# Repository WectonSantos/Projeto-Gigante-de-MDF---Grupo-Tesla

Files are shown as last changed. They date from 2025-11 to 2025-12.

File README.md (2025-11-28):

🛠️ Gigante de MDF – Projeto de Programação de Hardware 2025 - Grupo Tesla 

Projeto desenvolvido para a disciplina Programação de Hardware, utilizando o microcontrolador ATmega328P e envolvendo mecânica, eletrônica e firmware embarcado.

📌 Sobre o Projeto
O objetivo deste trabalho foi aplicar, na prática, os conteúdos estudados ao longo do semestre, criando um robô móvel (“Gigante de MDF”) capaz de:

• Locomover-se por meio de motores controlados via PWM
• Emitir feixes de laser vermelho (≤ 300 mW)
• Detectar impactos recebidos por lasers adversários
• Gerenciar um sistema de “vidas” por LEDs
• Realizar reações automáticas ao ser atingido

O foco principal do projeto foi o desenvolvimento do firmware, sem depender de shields prontos, bibliotecas externas não autorizadas ou soluções prontas da comunidade Arduino.

🚗 Estrutura Mecânica
O robô construído segue o conjunto de requisitos mecânicos:

• Dimensões máximas de 200 × 200 × 200 mm
• Sistema com 2 a 4 rodas, capaz de realizar movimentação no próprio eixo
• “Arma” laser posicionada no centro do robô, a 100 mm de altura
• Receptor de luz instalado ao lado direito da arma, com difusor de 20 mm
• Estrutura baseada em MDF, com cortes e montagem conforme projeto disponibilizado

🧠 Firmware e Programação
O firmware foi desenvolvido inteiramente do zero, com base no datasheet oficial da Microchip, sem bibliotecas prontas (exceto as eventualmente autorizadas pelo professor).
O código atende às seguintes especificações:

✔️ Microcontrolador
• ATmega328P
✔️ Requisitos de Programação
• Controle dos motores via PWM de hardware
• Laser temporizado por Timer
• Receptor de luz com rotina de interrupção
• Delay de segurança de 5s após cada acerto
• Gestão de LEDs e lógica de “vidas”
• Rotina de giro automático de 180°
• Reset de vidas via interrupção externa
• Código completamente documentado em Doxygen

📚 Documentação
A documentação completa do software foi gerada usando Doxygen e está disponível em:
/Documentacao/doxygen/

👥 Integrantes – Grupo Tesla
• Rafael Wippich
• Thiago Taveira
• Wecton Santos

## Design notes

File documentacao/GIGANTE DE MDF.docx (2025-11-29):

GIGANTE DE MDF

Rafael Wippich Jorge Alonso

Thiago Taveira Fernandes Amorim Justo

Wecton da Silva Santos

# 1. Introdução

O projeto Gigantes de MDF consiste no desenvolvimento completo de um robô móvel construído em MDF, equipado com um sistema de movimentação por motores DC controlados por PWM, um sistema de “arma laser” baseado em diodo emissor de luz vermelha e um sistema de detecção via receptor LDR com difusor.

O objetivo principal deste trabalho é aplicar, de forma prática, os conceitos aprendidos na disciplina de Programação de Hardware, utilizando o microcontrolador ATmega328p sem uso de shields ou módulos prontos, exceto componentes básicos necessários ao funcionamento.

Toda a eletrônica, firmware e documentação foram projetados, desenvolvidos e implementados pelo grupo.

# 2. Estrutura Mecânica

Apresentaremos a concepção mecânica do robô, seus limites dimensionais e a organização física dos componentes.

## 2.1 Dimensões e Construção

- Dimensões máximas: 200 × 200 × 200 mm

- Material utilizado: MDF de 3mm, cortado a laser.

- Modelo de referência utilizado: https://fabmanager.unisanta.br/#!/projects/estrutura-carro-robo

- Esquema mecânico utilizado no projeto:

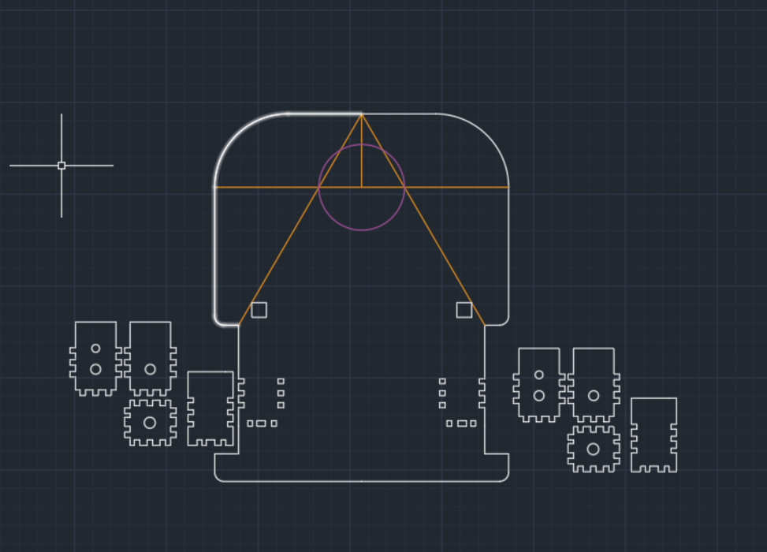
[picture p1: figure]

## 2.2 Sistema de Movimentação

- Quantidade de rodas: 2

- Motores utilizados: 2x Motor DC 3-6V

## 2.3 Sistema de Arma Laser

- Posição: centro do robô

- Altura em relação à base: 100 mm

- Tipo de laser utilizado: Laser vermelho

## 2.4 Sistema de Detecção

- Sensor de luz: LDR de 20 mm

- Posição: lado direito da arma laser

# 3. Arquitetura Eletrônica

- Microcontrolador: ATmega328P

- Driver de Motor: ci L293D

- Receptor de Luz: LDR 20mm

- Laser: Módulo Laser 650nm 5mw Md-lsr650nm

- Sistema de Vidas: 3x leds de 5mm

- Sistema de Movimentação: Módulo Bluetooth HC-06

- Sistema Reset: 1x Botão 6mm

- Diagrama Eletrônico Geral:

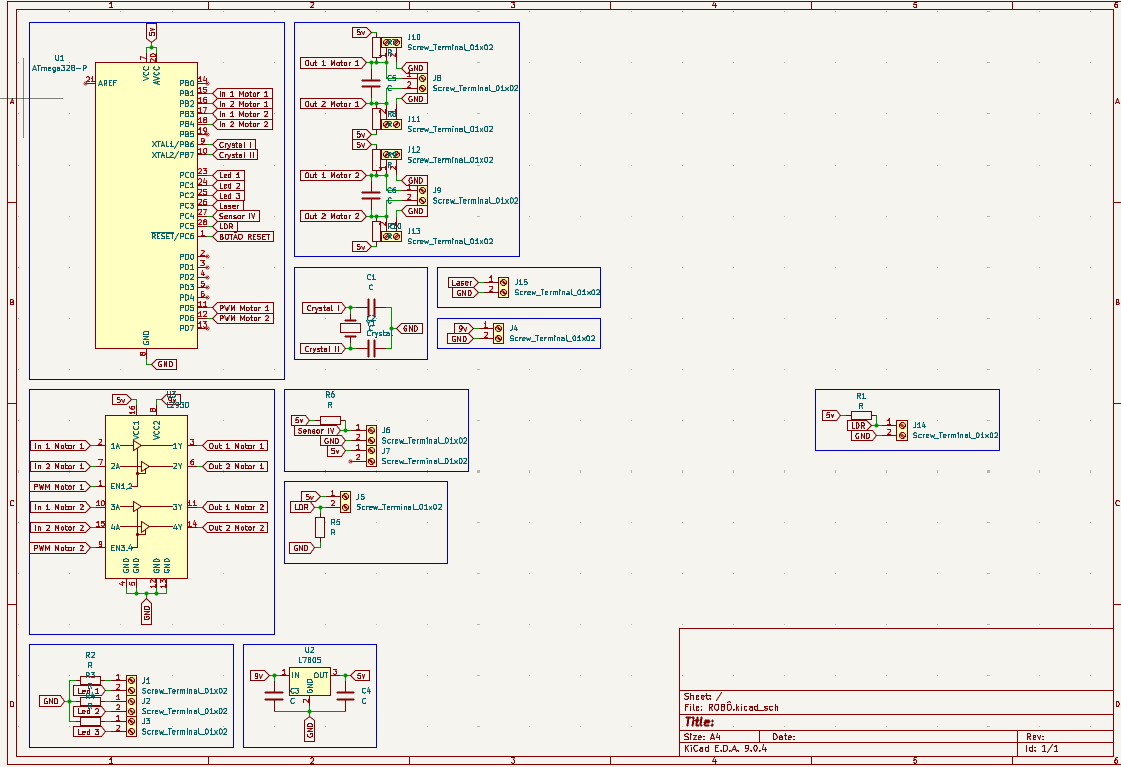
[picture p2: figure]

# 4. Firmware

O firmware desenvolvido para o projeto foi inteiramente escrito na linguagem C, utilizando acesso direto aos registradores do microcontrolador ATmega328P, conforme exigido pelo edital. A estrutura do código foi organizada em módulos independentes, permitindo fácil manutenção e leitura, além de garantir funcionamento eficiente e controle preciso dos periféricos essenciais.

Antes de ser gravado na placa, o firmware passou por uma etapa de simulação, que permitiu validar a lógica principal, testar estados da máquina de controle e verificar o comportamento dos módulos de acionamento, leitura de sensores e gerenciamento do laser. Essa fase reduziu significativamente retrabalhos na parte física, garantindo que os primeiros testes na plataforma real ocorressem com maior estabilidade. Após essa etapa, o código foi então carregado e testado diretamente no hardware, possibilitando ajustes finais de temporização, calibração e resposta do sistema.

Durante o desenvolvimento, foram utilizados os seguintes softwares:

- Microchip Studio: Ambiente principal de programação, gerenciamento do projeto, escrita, compilação e gravação do firmware no microcontrolador.

- SimulIDE: Ferramenta usada para simulação dos circuitos e execução preliminar do firmware antes da etapa prática.

- GitHub: Plataforma de versionamento utilizada para armazenar o código-fonte, manter o histórico de alterações, documentar o projeto e facilitar a colaboração entre os integrantes do grupo.

- Doxygen: Ferramenta utilizada para gerar automaticamente a documentação do firmware a partir de comentários estruturados inseridos diretamente no código-fonte. Com ela, foi possível organizar descrições de funções, módulos, estruturas, variáveis e fluxos internos do programa de forma clara e navegável.

Esse conjunto de ferramentas permitiu um desenvolvimento estruturado, controlado e eficiente, garantindo confiabilidade no firmware final entregue junto ao robô.

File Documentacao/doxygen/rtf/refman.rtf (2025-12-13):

Gigante de MDF - Grupo Tesla

AUTHOR
Versão 2.0

Sumário

Table of contents

Índice dos Arquivos
Lista de Arquivos
Esta é a lista de todos os arquivos e suas respectivas descrições:
C:/Users/Wecton/Desktop/Projeto-Gigante-de-MDF---Grupo-Tesla/main.c pagenum

Arquivos
Referência do Arquivo C:/Users/Wecton/Desktop/Projeto-Gigante-de-MDF---Grupo-Tesla/main.c
AAAAAAAAAAAAAAAAAAAA#include <avr/io.h>
#include <avr/interrupt.h>

#include <stdlib.h>

Funções
void ledsVida ()
void atualizaLedsVida ()
void motores ()
void pararMotores ()
void ligaMotoresHorario ()
void ligaMotoresAntiHorario ()
void giraEsquerda ()
void giraDireita ()
void girar360 ()
void laser ()
void timer1_init ()
void timer1_stop ()
ISR (TIMER1_COMPA_vect)
void timer2_init ()
void timer2_stop ()
ISR (TIMER2_COMPA_vect)
void adc_init ()
uint16_t adc_read (uint8_t canal)
void executaPedidoSequencia ()
void UART_Init ()
char UART_Receive ()
void UART_Transmit (char data)
void UART_SendString (const char *s)
void UART_SendInt (uint16_t v)
void controle ()
void botaoReset_init ()
ISR (INT1_vect)
void fim ()
int main (void)
Variáveis
uint8_t vidas = 3
uint8_t fimDeJogo = 0
volatile char comandoAtual = 'T'
volatile uint8_t estado = 0
volatile uint32_t contador = 0
volatile uint8_t seqRequisitada = 0

AAAAAAAAABAAAAAAAAABFunções
void adc_init ()
AAAAAAAAACAAAAAAAAAC
186 {
187 ADMUX = (1<<REFS0);
188 ADCSRA = (1<<ADEN)|(1<<ADPS2)|(1<<ADPS1)|(1<<ADPS0);
189 }
uint16_t adc_read (uint8_t canal)
AAAAAAAAADAAAAAAAAAD
191 {
192 ADMUX = (ADMUX & 0xF0) | (canal & 0x0F);
193 ADCSRA |= (1<<ADSC);
194 while (ADCSRA & (1<<ADSC));
195 return ADC;
196 }
void atualizaLedsVida ()
AAAAAAAAAEAAAAAAAAAE
32 {
33 if (vidas >= 3){
34 PORTC |= (1<<PC0) | (1<<PC1) | (1<<PC2);
35 }
36 else if (vidas == 2){
37 PORTC &= ~(1<<PC0);
38 PORTC |= (1<<PC1) | (1<<PC2);
39 }
40 else if (vidas == 1){
41 PORTC &= ~((1<<PC0)|(1<<PC1));
42 PORTC |= (1<<PC2);
43 }
44 else {
45 PORTC &= ~( (1<<PC0) | (1<<PC1) | (1<<PC2) );
46 fimDeJogo = 1;
47 }
48 }
void botaoReset_init ()
AAAAAAAAAFAAAAAAAAAF
263 {
264 DDRD &= ~(1<<PD3);
265 PORTD |= (1<<PD3);
266 EICRA |= (1<<ISC11);
267 EIMSK |= (1<<INT1);
268 }
void controle ()
AAAAAAAAAGAAAAAAAAAG
245 {
246 if (UCSR0A & (1<<RXC0))
247 comandoAtual = UDR0;
248
249 switch (comandoAtual) {
250 case 'F': case 'f': ligaMotoresHorario(); break;
251 case 'B': case 'b': ligaMotoresAntiHorario(); break;
252 case 'L': case 'l': giraEsquerda(); break;
253 case 'R': case 'r': giraDireita(); break;
254 case 'T': case 't': pararMotores(); break;
255 case 'X': case 'x': pararMotores(); break;
256
257 default: break;
258 }
259 }
void executaPedidoSequencia ()
AAAAAAAAAHAAAAAAAAAH
200 {
201 if (seqRequisitada) return;
202
203 seqRequisitada = 1;
204 estado = 1;
205 contador = 0;
206
207 girar360();
208 vidas--;
209
210 timer2_init();
211 }
void fim ()
AAAAAAAAAIAAAAAAAAAI
278 {
279 while(1){
280 pararMotores();
281 estado = 2;
282 PORTC &= ~(1<<PC3);
283 timer1_stop();
284 }
285 }
void giraDireita ()
AAAAAAAAAJAAAAAAAAAJ
97 {
98 // Esquerdo anti-horário
99 PORTD &= ~(1<<PD6);
100 PORTD &= ~(1<<PD5);
101
102 // Direito horário
103 PORTB |= (1<<PB3);
104 PORTB &= ~(1<<PB4);
105 }
void giraEsquerda ()
AAAAAAAAAKAAAAAAAAAK
86 {
87 // Esquerdo horário
88 PORTD |= (1<<PD5);
89 PORTD &= ~(1<<PD6);
90
91 // Direito anti-horário
92 PORTB &= ~(1<<PB4);
93 PORTB &= ~(1<<PB3);
94
95 }
void girar360 ()
AAAAAAAAALAAAAAAAAAL
107 {
108 // Esquerdo horário
109 PORTD |= (1<<PD5);
110 PORTD &= ~(1<<PD6);
111
112 // Direito anti-horário
113 PORTB |= (1<<PB4);
114 PORTB &= ~(1<<PB3);
115 }
ISR (INT1_vect )
AAAAAAAAAMAAAAAAAAAM
270 {
271 if (estado == 2) return;
272 vidas = 3;
273 atualizaLedsVida();
274 }
ISR (TIMER1_COMPA_vect )
AAAAAAAAANAAAAAAAAAN
137 {
138 if (estado == 0){
139 PORTC ^= (1<<PC3);
140 }
141 }
ISR (TIMER2_COMPA_vect )
AAAAAAAAAOAAAAAAAAAO
158 {
159 if (estado == 0 && seqRequisitada == 0) return;
160
161 contador++;
162
163 if (estado == 1){
164 if (contador >= 1000){
165 pararMotores();
166 PORTC &= ~(1<<PC3);
167 timer1_stop();
168 estado = 2;
169 contador = 0;
170 }
171 }
172 else if (estado == 2){
173 if (contador >= 5000){
174 estado = 0;
175 seqRequisitada = 0;
176 contador = 0;
177 timer1_init();
178 timer2_stop();
179 PORTC &= ~(1<<PC3);
180 }
181 }
182 }
void laser ()
AAAAAAAAAPAAAAAAAAAP
120 {
121 DDRC |= (1<<PC3);
122 }
void ledsVida ()
AAAAAAAAAQAAAAAAAAAQ
26 {
27 DDRC |= (1 << PC0) | (1 << PC1) | (1 << PC2);
28
29 PORTC |= (1<<PC0) | (1<<PC1) | (1<<PC2);
30 }
void ligaMotoresAntiHorario ()
AAAAAAAAARAAAAAAAAAR
76 {
77 // Esquerdo anti-horário
78 PORTD |= (1<<PD6);
79 PORTD &= ~(1<<PD5);
80
81 // Direito anti-horário
82 PORTB |= (1<<PB4);
83 PORTB &= ~(1<<PB3);
84 }
void ligaMotoresHorario ()
AAAAAAAAASAAAAAAAAAS
66 {
67 // Motor esquerdo horário
68 PORTD |= (1<<PD5);
69 PORTD &= ~(1<<PD6);
70
71 // Motor direito horário
72 PORTB |= (1<<PB3);
73 PORTB &= ~(1<<PB4);
74 }
int main (void )
AAAAAAAAATAAAAAAAAAT
289 {
290 ledsVida();
291 motores();
292 laser();
293 adc_init();
294 timer1_init();
295 UART_Init();
296 botaoReset_init();
297
298 uint16_t valorLDR;
299 uint8_t luzAlta = 0;
300
301 while (1)
302 {
303 // BLOQUEIA LEITURA DO LDR DURANTE SEQUÊNCIA
304 if (estado == 0) {
305
306 valorLDR = adc_read(5);
307
308 if (valorLDR > 900 && seqRequisitada == 0) {
309 executaPedidoSequencia();
310 }
311
312 // permite controle bluetooth só no modo normal
313 controle();
314 }
315
316 atualizaLedsVida();
317
318 if (fimDeJogo)
319 fim();
320 }
321
322 }
void motores ()
AAAAAAAAAUAAAAAAAAAU
52 {
53 DDRB |= (1<<PB3) | (1<<PB4); // Motor direito
54 DDRD |= (1<<PD5) | (1<<PD6); // Motor esquerdo
55
56 // Inicialmente desligado
57 PORTB &= ~((1<<PB3)|(1<<PB4));
58 PORTD &= ~((1<<PD5)|(1<<PD6));
59 }
void pararMotores ()
AAAAAAAAAVAAAAAAAAAV
61 {
62 PORTB &= ~((1<<PB3)|(1<<PB4));
63 PORTD &= ~((1<<PD5)|(1<<PD6));
64 }
void timer1_init ()
AAAAAAAAAWAAAAAAAAAW
124 {
125 TCCR1B |= (1<<WGM12);
126 OCR1A = 15624;
127 TIMSK1 |= (1<<OCIE1A);
128 TCCR1B |= (1<<CS12)|(1<<CS10);
129 sei();
130 }
void timer1_stop ()
AAAAAAAAAXAAAAAAAAAX
132 {
133 TIMSK1 &= ~(1<<OCIE1A);
134 TCCR1B = 0;
135 }
void timer2_init ()
AAAAAAAAAYAAAAAAAAAY
145 {
146 TCCR2A = (1<<WGM21);
147 OCR2A = 249;
148 TIMSK2 |= (1<<OCIE2A);
149 TCCR2B = (1<<CS22);
150 sei();
151 }
void timer2_stop ()
AAAAAAAAAZAAAAAAAAAZ
153 {
154 TIMSK2 &= ~(1<<OCIE2A);
155 TCCR2B = 0;
156 }
void UART_Init ()
AAAAAAAABAAAAAAAAABA
215 {
216 uint16_t ubrr = 103;
217 UBRR0H = (unsigned char)(ubrr>>8);
218 UBRR0L = (unsigned char)ubrr;
219 UCSR0B = (1<<RXEN0)|(1<<TXEN0);
220 UCSR0C = (1<<UCSZ01)|(1<<UCSZ00);
221 }
char UART_Receive ()
AAAAAAAABBAAAAAAAABB
223 {
224 while (!(UCSR0A & (1<<RXC0)));
225 return UDR0;
226 }
void UART_SendInt (uint16_t v)
AAAAAAAABCAAAAAAAABC
237 {
238 char buf[10];
239 itoa(v, buf, 10);
240 UART_SendString(buf);
241 }
void UART_SendString (const char * s)
AAAAAAAABDAAAAAAAABD
233 {
234 while(*s) UART_Transmit(*s++);
235 }
void UART_Transmit (char data)
AAAAAAAABEAAAAAAAABE
228 {
229 while (!(UCSR0A&(1<<UDRE0)));
230 UDR0 = data;
231 }

AAAAAAAABFAAAAAAAABFVariáveis
volatile char comandoAtual = 'T'
AAAAAAAABGAAAAAAAABGvolatile uint32_t contador = 0
AAAAAAAABHAAAAAAAABHvolatile uint8_t estado = 0
AAAAAAAABIAAAAAAAABIuint8_t fimDeJogo = 0
AAAAAAAABJAAAAAAAABJvolatile uint8_t seqRequisitada = 0
AAAAAAAABKAAAAAAAABKuint8_t vidas = 3
AAAAAAAABLAAAAAAAABL

Referência do Arquivo C:/Users/Wecton/Desktop/Projeto-Gigante-de-MDF---Grupo-Tesla/README.md
AAAAAAAABMAAAAAAAABM
Sumário
INDEX

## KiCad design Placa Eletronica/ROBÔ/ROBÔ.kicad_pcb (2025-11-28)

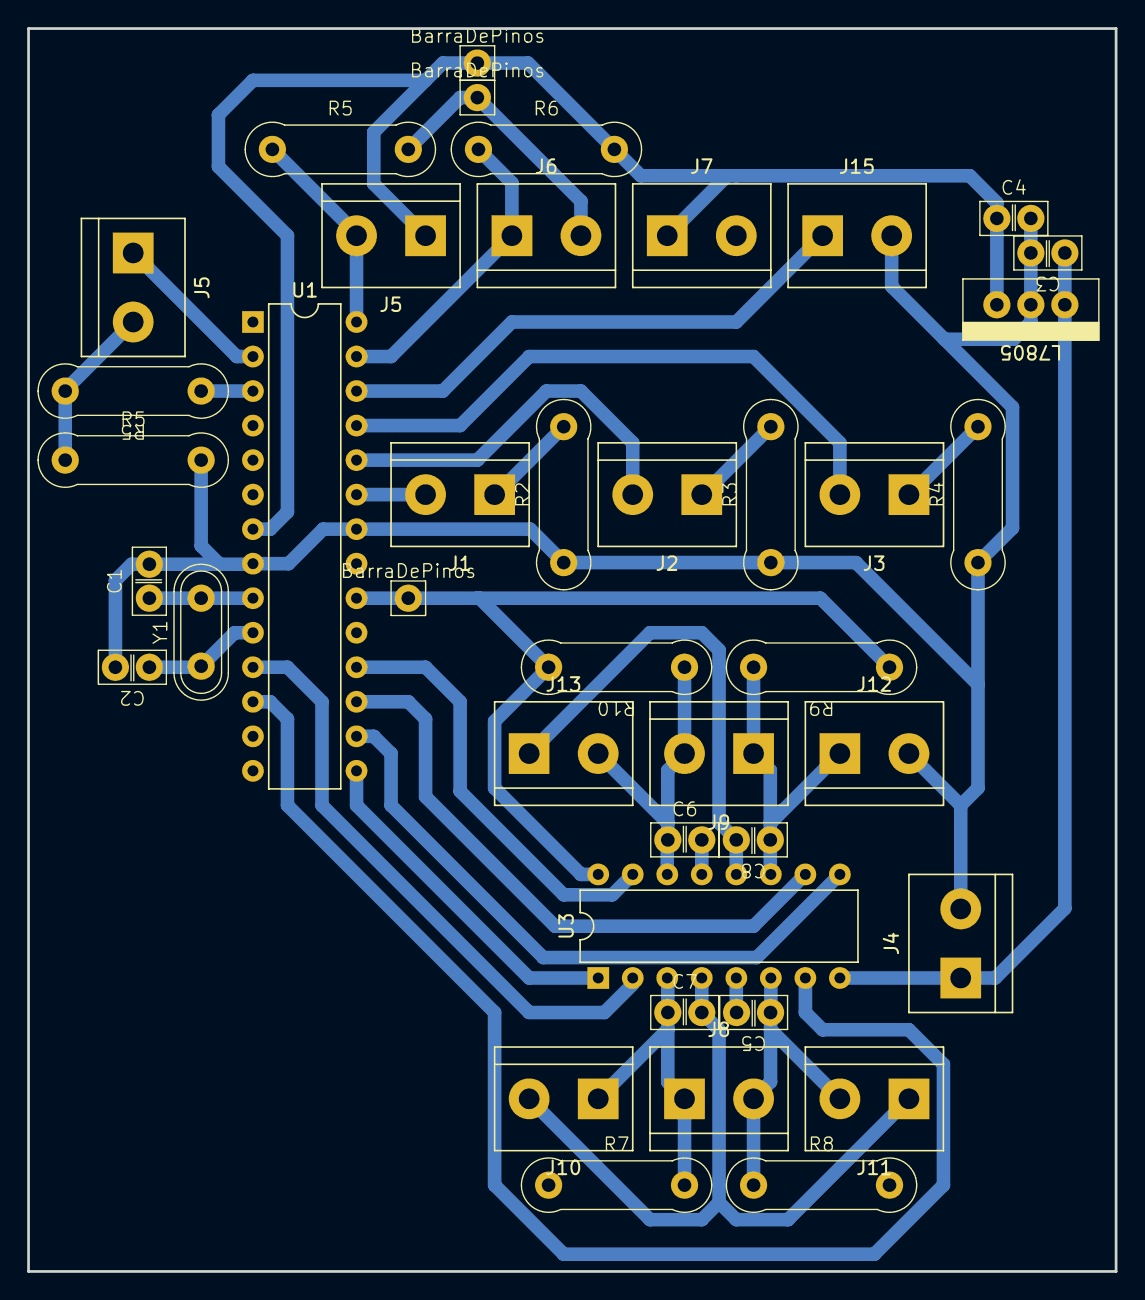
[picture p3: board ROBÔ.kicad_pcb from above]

Board: 2 copper layers, 80.0 x 91.4 mm, 41 parts (0 on the bottom side), 27 nets.

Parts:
BarraDePinos: DistânciaEntreFuros:_2,54mm; BarraDePinos
BarraDePinos#2, BarraDePinos#3: DistânciaEntreFuros:_2,54mm; BarraDePinos
C1, C2, C3, C4, C5, C6, C7, C8: C; CapacitorCerâmico-100nF_ou_0,1uF
J1, J2, J3, J4, J5, J5#2, J6, J7, J8, J9, J10, J11, J12, J13, J15: Screw_Terminal_01x02; TerminalBlock_bornier-2_P5.08mm
R2, R3, R4, R5, R5#2, R5#3, R6, R7, R8, R9, R10: R; Resistor
U1: ATmega328-P; DIP-28_W7.62mm
U2: L7805; ReguladorDeTensão-L7805_5V
U3: L293D; DIP-16_W7.62mm
Y1: Crystal; CristalOscilador16MHz

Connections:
5v: BarraDePinos#2.1, BarraDePinos#3.1, C4.IN, J5.1, J7.1, R6.2, R7.1, R8.2, R9.1, R10.2, U1.7 (VCC), U1.20 (AVCC), U2.OUTPUT, U3.16 (VCC1)
9v: C3.IN, J4.1, U2.INPUT, U3.8 (VCC2)
Crystal I: C1.IN, U1.9 (XTAL1/PB6), Y1.2
Crystal II: C2.IN, U1.10 (XTAL2/PB7), Y1.1
GND: BarraDePinos.1, C1.GND, C2.GND, C3.GND, C4.GND, C5.GND, C6.GND, C7.GND, C8.GND, J4.2, J6.2, J10.2, J11.1, J12.2, J13.1, J15.2, R2.1, R3.1, R4.1, R5#2.2, R5#3.2, U1.8 (GND), U1.22 (GND), U2.GND, U3.4 (GND), U3.5 (GND), U3.12 (GND), U3.13 (GND)
In 1 Motor 1: U1.11 (PD5), U3.2 (1A)
In 1 Motor 2: U1.17 (PB3), U3.10 (3A)
In 2 Motor 1: U1.12 (PD6), U3.7 (2A)
In 2 Motor 2: U1.18 (PB4), U3.15 (4A)
LDR: J5.2, R5#2.1, U1.28 (PC5)
Laser: J15.1, U1.26 (PC3)
Led 1: J1.2, U1.23 (PC0)
Led 2: J2.2, U1.24 (PC1)
Led 3: J3.2, U1.25 (PC2)
unnamed: J1.1, R2.2
unnamed: J2.1, R3.2
unnamed: J3.1, R4.2
Out 1 Motor 1: C7.IN, J8.1, J10.1, R7.2, U3.3 (1Y)
Out 1 Motor 2: C8.IN, J9.1, J12.1, R9.2, U3.11 (3Y)
Out 2 Motor 1: C5.IN, J8.2, J11.2, R8.1, U3.6 (2Y)
Out 2 Motor 2: C6.IN, J9.2, J13.2, R10.1, U3.14 (4Y)
PWM Motor 1: U1.15 (PB1), U3.1 (EN1,2)
PWM Motor 2: U1.16 (PB2), U3.9 (EN3,4)
RX: J5#2.1, U1.2 (PD0)
Sensor IV: J6.1, R6.1, U1.27 (PC4)
TX: R5.1, U1.3 (PD1)
Temp: J5#2.2, R5.2, R5#3.1

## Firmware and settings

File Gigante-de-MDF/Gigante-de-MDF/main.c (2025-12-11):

/*
 * projeto-prog-hardware.c
 *
 * Created: 13/10/2025 22:14:15
 * Author : Wecton
 */ 

#include <avr/io.h>
#include <avr/interrupt.h>
#include <stdlib.h> // APENAS PARA RETORNAR OS VALORES INT SEM ERROS NO BLUETOOTH, UTILIZANDO itoa

uint8_t vidas = 3;
uint8_t fimDeJogo = 0;
volatile char comandoAtual = 'T'; 

// SEQUÊNCIA: 0 = NORMAL, 1 = GIRANDO 1S, 2 = BLOQUEADO 5S
volatile uint8_t estado = 0;
volatile uint32_t contador = 0; // // CONTADOR EM MS
volatile uint8_t seqRequisitada = 0;// FLAG DE REQUISIÇÃO DA SEQUÊNCIA

// ROTINA QUE CONFIGURA OS LEDS DE VIDA
void ledsVida(){
	DDRC |= (1 << PC0); // LED 1 (SAÍDA)
	DDRC |= (1 << PC1); // LED 2 (SAÍDA)
	DDRC |= (1 << PC2); // LED 3 (SAÍDA)
	
	PORTC |= (1<< PC0); // LIGANDO LED 1
	PORTC |= (1<< PC1); // LIGANDO LED 1
	PORTC |= (1<< PC2); // LIGANDO LED 1
}
// ROTINA QUE CONFIGURA OS MOTORES
void motores() {
	DDRB |= (1<<PB1) | (1<<PB2) | (1<<PB3) | (1<<PB4);
	DDRD |= (1<<PD5) | (1<<PD6);

	// Desliga tudo ANTES de qualquer comando Bluetooth
	PORTB &= ~((1<<PB1)|(1<<PB2)|(1<<PB3)|(1<<PB4));
	OCR0A = 0;
	OCR0B = 0;
}


// BOTÕES PREVIAMENTE QUE SERÃO TROCADOS PELO VALOR RECEBIDO DO CONTROLE
void botoes(){
	DDRB &= ~(1 << PB6);
	DDRB &= ~(1 << PB0);
	DDRD &= ~(1 << PD4);
}

// ROTINA QUE CONFIGURA O LASER
void laser(){
	DDRC |= (1 << PC3); // LASER PORTA C3 (CTC)
}

// ROTINA LDR

void adc_init(void) {
	ADMUX = (1 << REFS0); 		
	//ADMUX &= ~(1 << ADLAR);   // alinhamento à direita (modo normal)

	ADCSRA = (1 << ADEN) | (1 << ADPS2) | (1 << ADPS1) | (1 << ADPS0); // prescaler 128 (16MHz/128=125kHz)
	//DIDR0 = (1 << ADC4D);
	//DDRC &= ~(1 << PC4); 
}

uint16_t adc_read(uint8_t canal) {
	//ADMUX = (1 << REFS0) | (canal & 0x0F);
	ADMUX = (ADMUX & 0xF0) | (canal & 0x0f);
	ADCSRA |= (1 << ADSC);
	while (ADCSRA & (1 << ADSC));
	return ADC; 
}

void atualizaLedsVida() {
	if (vidas >= 3){
		PORTC |= (1 << PC0) | (1 << PC1) | (1 << PC2);
	}else if (vidas == 2) {
		PORTC |= (1 << PC1) | (1 << PC2);
		PORTC &= ~(1 << PC0);
	}else if (vidas == 1) {
		PORTC |= (1 << PC2);
		PORTC &= ~((1 << PC0) | (1 << PC1));
	}else{
		PORTC &= ~((1 << PC0) | (1 << PC1) | (1 << PC2));
		fimDeJogo = 1;
	}
}
// FIM ROTINA LDR

// ROTINA DOS MOTORES
void ligaMotoresHorario(){		
    // Motor esquerdo horário
    PORTB |=  (1<<PB1);
    PORTB &= ~(1<<PB2);

    // Motor direito horário
    PORTB |=  (1<<PB3);
    PORTB &= ~(1<<PB4);
}

void ligaMotoresAntiHorario(){
    // Motor esquerdo anti-horário
    PORTB |=  (1<<PB2);
    PORTB &= ~(1<<PB1);

    // Motor direito anti-horário
    PORTB |=  (1<<PB4);
    PORTB &= ~(1<<PB3);
}

void giraEsquerda() {
    // Motor esquerdo anti-horário
    PORTB |=  (1<<PB2);
    PORTB &= ~(1<<PB1);

    // Motor direito horário
    PORTB |=  (1<<PB3);
    PORTB &= ~(1<<PB4);
}

void giraDireita() {
    // Motor esquerdo horário
    PORTB |=  (1<<PB1);
    PORTB &= ~(1<<PB2);

    // Motor direito anti-horário
    PORTB |=  (1<<PB4);
    PORTB &= ~(1<<PB3);
}

void girar360() {
	// Motor 1 horário: IN1=1, IN2=0
	PORTB |=  (1<<PB1);
	PORTB &= ~(1<<PB2);

	// Motor 2 anti-horário: IN3=0, IN4=1
	PORTB &= ~(1<<PB3);
	PORTB |=  (1<<PB4);

	// PWM
	OCR0A = 200;  // motor 2
	OCR0B = 200;  // motor 1
}


void curvaDireita(){
	PORTB |= (1<<PB1)|(1<<PB3);
	PORTB &= ~((1<<PB2)|(1<<PB4));	
	// LIGA PWM
	OCR0A = 255;
	OCR0B = 77;
}
void curvaEsquerda(){
	PORTB |= (1<<PB1)|(1<<PB3);
	PORTB &= ~((1<<PB2)|(1<<PB4));
	// LIGA PWM
	OCR0A = 77;
	OCR0B = 255;
}

void pararMotores() {
	OCR0A = 0;
	OCR0B = 0;
	PORTB &= ~((1<<PB1)|(1<<PB2)|(1<<PB3)|(1<<PB4));
}


void verificaSentido(){
	if (PIND & (1 << PD4)) {
		ligaMotoresHorario();
	}
	else if (PINB & (1 << PB0)) {
		ligaMotoresAntiHorario();
	}//else if (PINB & (1 << PB6)){
		//ligaMotoresMeiaForca();  
	//}
	else {
		OCR0A = 0;
		OCR0B = 0;
		PORTB &= ~((1 << PB7) | (1 << PB5) | (1 << PB4) | (1 << PB0));
	}	
}
//FIM ROTINA DOS MOTORES

//ROTINA LASER MODO CTC
void timer1_init() {
	TCCR1B |= (1 << WGM12);  // CTC
	OCR1A = 15624;           // 1 SEGUNDO P/ PRESCALER 1024
	TIMSK1 |= (1 << OCIE1A); 
	TCCR1B |= (1 << CS12) | (1 << CS10); // PRESCALER 1024
	sei();
}

// DESLIGA O TIMER1 (PARA NÃO ALTERAR O LASER DURANTE BLOQUEIO)
void timer1_stop() {
	TIMSK1 &= ~(1 << OCIE1A);
	TCCR1B = 0;
}
// PISCA LASER SE ESTIVER EM MODO NORMAL == SEM BLOQUEIO
ISR(TIMER1_COMPA_vect) {
	if (estado == 0){
		PORTC ^= (1 << PC3);
	}
	//PORTC ^= (1 << PC3);  // ALTERNA ESTADO DO LED
}

// TICKS DE 1 MS PARA GERENCIAR A SEQUÊNCIA SEM DELAY
void timer2_init(void){
	TCCR2A = (1 << WGM21); // CTC
	OCR2A = 249; // COM PRESCALER 64 => 1MS
	TIMSK2 |= (1 << OCIE2A);
	TCCR2B = (1 << CS22); // PRESCALER 64
	sei();
}
// DESLIGA O TIMER2
void timer2_stop(void){
	TIMSK2 &= ~(1 << OCIE2A);
	TCCR2B = 0;
}

// CONTROLE DA SEQUÊNCIA (1S GIRANDO, 5S BLOQUEADO)
ISR(TIMER2_COMPA_vect){

	if (estado == 0 && seqRequisitada == 0) return; // SE NÃO HOUVER SEQUENCIA NÃO FAZ NADA

	contador++; 

	if (estado == 1) {
		// LDR RECEBEU VALOR ALTO E ESPERA 1S PARA COMPLETAR O GIRO 360
		if (contador >= 1000) {
			// APÓS O GIRO PARA MOTORES, DESLIGA LASER, INICIA BLOQUEIO
			pararMotores(); 
			PORTC &= ~(1 << PC3);// DESLIGA LASER
			timer1_stop(); // GARANTE QUE O TIMER1 NÃO VAI MAIS PISCAR
			estado = 2; // ALTERNA PARA O ESTADO DE BLOQUEIO
			contador = 0; 
		}
	} else if (estado == 2) { // ESTÁ BLOQUEADO, AGUARDA 5S
		if (contador >= 5000) {
			// AO SAIR DO BLOQUEIO RETORNA AO MODO NORMAL
			estado = 0;
			contador = 0;
			seqRequisitada = 0;
			timer1_init(); // REATIVA O PISCA DO LASER
			PORTC &= ~(1 << PC3);
			timer2_stop();
		}
	}
}
void executaPedidoSequencia(void){
	if (seqRequisitada) return; // JÁ TEM UMA SEQUÊNCIA ATIVA
	seqRequisitada = 1;
	estado = 1; // ENTRA NO GIRO DE 360 POR 1S
	contador = 0;
	comandoAtual = 'a';
	girar360();
	vidas--;
	timer2_init(); // INICIA CONTAGEM  
}
//ROTINA CONTROLE BLUETOOTH
// INICIALIZA UART EM 9600 BPS
void UART_Init(void) {
	uint16_t ubrr = 103; // 9600 BPS p/ 16 MHz
	UBRR0H = (unsigned char)(ubrr >> 8);
	UBRR0L = (unsigned char)ubrr;
	UCSR0B = (1 << RXEN0) | (1 << TXEN0);       // HABILITA RX E TX
	UCSR0C = (1 << UCSZ01) | (1 << UCSZ00);     // 8 BITS DE DADOS
}
// RECEBE UM CARACTERA
char UART_Receive(void) {
	while (!(UCSR0A & (1 << RXC0))); // ESPERA DADO CHEGAR
	return UDR0;
}
// ENVIA 1 CARACTERE PELA UART
void UART_Transmit(char data) {
	while (!(UCSR0A & (1 << UDRE0))); // ESPERA BUFFER ESVAZIAR
	UDR0 = data;
}

// ENVIA STRING PELA UART
void UART_SendString(const char *str) {
	while (*str) {
		UART_Transmit(*str++);
	}
}

// ENVIA INT COMO TEXTO PARA UART

void UART_SendInt(uint16_t value) {
	char buffer[10];
	itoa(value, buffer, 10);     // VALOR ? BUFFER ? BASE 10
	UART_SendString(buffer);
}

void controle() {

	if (UCSR0A & (1<<RXC0)) {   // SÓ LÊ SE TIVER ALGO EM UART
		comandoAtual = UDR0;    // SALVA NOVO COMANDO
	}

	switch (comandoAtual) {

		case 'F':
		case 'f':
		ligaMotoresHorario();
		break;

		case 'B':
		case 'b':
		ligaMotoresAntiHorario();
		break;

		case 'L':
		case 'l':
		giraEsquerda();
		break;

		case 'R':
		case 'r':
		giraDireita();
		break;

		case 'T':   
		case 't':
		pararMotores();
		break;
		
		case 'X':
		case 'x':
			if (estado == 2) return;
			vidas = 3;
			atualizaLedsVida();
		default:
		// comando inválido -> não muda nada
		break;
	}
}
//FIM ROTINA CONTROLE BLUETOOTH

// RESET
void botaoReset_init() {
	DDRD &= ~(1 << PD3);   // ENTRADA
	PORTD |= (1 << PD3);   // PULL-UP

	EICRA |= (1 << ISC11); // BORDA DE DESCIDA
	EIMSK |= (1 << INT1);  // HABILITE INT1
}

ISR(INT1_vect) {
	// IMPEDE RESET DURANTE O BLOQUEIO
	if (estado == 2) return;
	vidas = 3;
	atualizaLedsVida();
}


void fim(){
	while(1){
		pararMotores();
		estado = 2;
		PORTC &= ~(1 << PC3);// DESLIGA LASER
		timer1_stop(); // GARANTE QUE O TIMER1 NÃO VAI MAIS PISCAR
	}
}

int main(void)
{
	// SETANDO TODAS AS PORTAS
	ledsVida(); 
	motores(); 
	//botoes(); 
	laser(); 
	
	// ROTINA LDR
	adc_init();
	uint16_t valorLDR;
	uint8_t luzAlta = 0; 
	// FIM ROTINA LDR

    // FAST PWM NO TIMER 0
    TCCR0A = (1<<COM0A1)|(1<<COM0B1)|(1<<WGM01)|(1<<WGM00);
    TCCR0B = (1<<CS01);    // PRESCALER = 8

    //GARANTE QUE VAI COMEÇAR COM MOTORES DESLIGADOS
    OCR0A = 0; 
    OCR0B = 0;  
	
	//LASER
	timer1_init();

	// CONTROLE 
	UART_Init();
	
    // GARANTE SAÍDAS LIMPAS
	PORTB &= ~((1 << PB1) | (1 << PB2) | (1 << PB3) | (1 << PB4));	
	
	// RESET
	
	botaoReset_init();

    while (1) 
    {
		//ROTINA LDR
		valorLDR = adc_read(5); // LÊ O ADC5 (PC5)
		// debug ldr
		UART_SendString("LDR = ");
		UART_SendInt(valorLDR);
		UART_SendString("\r\n");	
		// debug ldr

		if (valorLDR > 100) {
			luzAlta = 1; // LDR RECEBEU VALOR ALTO
			executaPedidoSequencia();
		}else{
			luzAlta = 0;
		}
		if (luzAlta) {
			// só perde vida se NÃO estiver executando a sequência
			if (vidas > 0 && seqRequisitada == 0 && estado == 0) {
				vidas--;
				executaPedidoSequencia();  // inicia o giro + bloqueio
			}

			} else {
			luzAlta = 0;
		}
		atualizaLedsVida();
		
		// SOMENTE ACEITA CONTROLES QUANDO NÃO ESTIVER EM BLOQUEIO
        if (estado == 0){
			verificaSentido();
			if (PINB & (1 << PB6)){
		        executaPedidoSequencia();
				vidas--;
	        }			
			controle();  // CHAMA CONTROLE    
		}
		if(fimDeJogo == 1){
			fim();
		}
		
									
    }
}

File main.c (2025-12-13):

#include <avr/io.h>
#include <avr/interrupt.h>
#include <stdlib.h> 

uint8_t vidas = 3;
uint8_t fimDeJogo = 0;
volatile char comandoAtual = 'T'; 

// 0 = normal, 1 = girando por 1s, 2 = bloqueado 5s
volatile uint8_t estado = 0;
volatile uint32_t contador = 0;
volatile uint8_t seqRequisitada = 0;

// ---------------- LEDS VIDA ----------------
void ledsVida(){
	DDRC |= (1 << PC0) | (1 << PC1) | (1 << PC2);

	PORTC |= (1<<PC0) | (1<<PC1) | (1<<PC2);
}

void atualizaLedsVida() {
	if (vidas >= 3){
		PORTC |= (1<<PC0) | (1<<PC1) | (1<<PC2);
	}
	else if (vidas == 2){
		PORTC &= ~(1<<PC0);
		PORTC |= (1<<PC1) | (1<<PC2);
	}
	else if (vidas == 1){
		PORTC &= ~((1<<PC0)|(1<<PC1));
		PORTC |= (1<<PC2);
	}
	else {
		PORTC &= ~( (1<<PC0) | (1<<PC1) | (1<<PC2) );
		fimDeJogo = 1;
	}
}


// ---------------- MOTORES (SEM PWM) ----------------
void motores(){
	DDRB |= (1<<PB3) | (1<<PB4);   // Motor direito
	DDRD |= (1<<PD5) | (1<<PD6);   // Motor esquerdo

	// Inicialmente desligado
	PORTB &= ~((1<<PB3)|(1<<PB4));
	PORTD &= ~((1<<PD5)|(1<<PD6));
}

void pararMotores(){
	PORTB &= ~((1<<PB3)|(1<<PB4));
	PORTD &= ~((1<<PD5)|(1<<PD6));
}

void ligaMotoresHorario(){
	// Motor esquerdo horário
	PORTD |=  (1<<PD5);
	PORTD &= ~(1<<PD6);

	// Motor direito horário
	PORTB |=  (1<<PB3);
	PORTB &= ~(1<<PB4);
}

void ligaMotoresAntiHorario(){
	// Esquerdo anti-horário
	PORTD |=  (1<<PD6);
	PORTD &= ~(1<<PD5);

	// Direito anti-horário
	PORTB |=  (1<<PB4);
	PORTB &= ~(1<<PB3);
}

void giraEsquerda(){
  	// Esquerdo horário
	PORTD |=  (1<<PD5);
	PORTD &= ~(1<<PD6);

	// Direito anti-horário
	PORTB &=  ~(1<<PB4);
	PORTB &= ~(1<<PB3);

}

void giraDireita(){
	// Esquerdo anti-horário
	PORTD &=  ~(1<<PD6);
	PORTD &= ~(1<<PD5);

	// Direito horário
	PORTB |=  (1<<PB3);
	PORTB &= ~(1<<PB4);
}

void girar360(){
	// Esquerdo horário
	PORTD |=  (1<<PD5);
	PORTD &= ~(1<<PD6);

	// Direito anti-horário
	PORTB |=  (1<<PB4);
	PORTB &= ~(1<<PB3);
}



// ---------------- LASER ----------------
void laser(){
	DDRC |= (1<<PC3);
}

void timer1_init(){
	TCCR1B |= (1<<WGM12);  
	OCR1A = 15624;
	TIMSK1 |= (1<<OCIE1A);
	TCCR1B |= (1<<CS12)|(1<<CS10);
	sei();
}

void timer1_stop(){
	TIMSK1 &= ~(1<<OCIE1A);
	TCCR1B = 0;
}

ISR(TIMER1_COMPA_vect){
	if (estado == 0){
		PORTC ^= (1<<PC3);
	}
}


// ---------------- TIMER2 - CONTROLE DE SEQUÊNCIA ----------------
void timer2_init(){
	TCCR2A = (1<<WGM21);
	OCR2A = 249;
	TIMSK2 |= (1<<OCIE2A);
	TCCR2B = (1<<CS22);
	sei();
}

void timer2_stop(){
	TIMSK2 &= ~(1<<OCIE2A);
	TCCR2B = 0;
}

ISR(TIMER2_COMPA_vect){
	if (estado == 0 && seqRequisitada == 0) return;

	contador++;

	if (estado == 1){
		if (contador >= 1000){
			pararMotores();
			PORTC &= ~(1<<PC3);
			timer1_stop();
			estado = 2;
			contador = 0;
		}
	}
	else if (estado == 2){
		if (contador >= 5000){
			estado = 0;
			seqRequisitada = 0;
			contador = 0;
			timer1_init();
			timer2_stop();
			PORTC &= ~(1<<PC3);
		}
	}
}


// ---------------- ADC / LDR ----------------
void adc_init(){
	ADMUX = (1<<REFS0);
	ADCSRA = (1<<ADEN)|(1<<ADPS2)|(1<<ADPS1)|(1<<ADPS0);
}

uint16_t adc_read(uint8_t canal){
	ADMUX = (ADMUX & 0xF0) | (canal & 0x0F);
	ADCSRA |= (1<<ADSC);
	while (ADCSRA & (1<<ADSC));
	return ADC;
}


// ---------------- SEQUÊNCIA LDR ----------------
void executaPedidoSequencia(){
	if (seqRequisitada) return;

	seqRequisitada = 1;
	estado = 1;
	contador = 0;

	girar360();
	vidas--;

	timer2_init();
}


// ---------------- UART ----------------
void UART_Init(){
	uint16_t ubrr = 103;
	UBRR0H = (unsigned char)(ubrr>>8);
	UBRR0L = (unsigned char)ubrr;
	UCSR0B = (1<<RXEN0)|(1<<TXEN0);
	UCSR0C = (1<<UCSZ01)|(1<<UCSZ00);
}

char UART_Receive(){
	while (!(UCSR0A & (1<<RXC0)));
	return UDR0;
}

void UART_Transmit(char data){
	while (!(UCSR0A&(1<<UDRE0)));
	UDR0 = data;
}

void UART_SendString(const char* s){
	while(*s) UART_Transmit(*s++);
}

void UART_SendInt(uint16_t v){
	char buf[10];
	itoa(v, buf, 10);
	UART_SendString(buf);
}


// ---------------- CONTROLE BLUETOOTH ----------------
void controle(){
	if (UCSR0A & (1<<RXC0))
		comandoAtual = UDR0;

	switch (comandoAtual) {
		case 'F': case 'f': ligaMotoresHorario(); break;
		case 'B': case 'b': ligaMotoresAntiHorario(); break;
		case 'L': case 'l': giraEsquerda(); break;
		case 'R': case 'r': giraDireita(); break;
		case 'T': case 't': pararMotores(); break;
		case 'X': case 'x': pararMotores(); break;

		default: break;
	}
}


// ---------------- BOTÃO RESET ----------------
void botaoReset_init(){
	DDRD &= ~(1<<PD3);
	PORTD |= (1<<PD3);
	EICRA |= (1<<ISC11);
	EIMSK |= (1<<INT1);
}

ISR(INT1_vect){
	if (estado == 2) return;
	vidas = 3;
	atualizaLedsVida();
}


// ---------------- FIM DE JOGO ----------------
void fim(){
	while(1){
		pararMotores();
		estado = 2;
		PORTC &= ~(1<<PC3);
		timer1_stop();
	}
}


// ------------------- MAIN -------------------
int main(void){
	ledsVida();
	motores();
	laser();
	adc_init();
	timer1_init();
	UART_Init();
	botaoReset_init();

	uint16_t valorLDR;
	uint8_t luzAlta = 0;

while (1)
{
    // BLOQUEIA LEITURA DO LDR DURANTE SEQUÊNCIA
    if (estado == 0) {

        valorLDR = adc_read(5);

        if (valorLDR > 900 && seqRequisitada == 0) {
            executaPedidoSequencia();
        }

        // permite controle bluetooth só no modo normal
        controle();
    }

    atualizaLedsVida();

    if (fimDeJogo)
        fim();
}

}

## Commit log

2025-11-27 correção bug não girar 360
    [main.c]
2025-11-28 add placa
    [ROBÔ.kicad_pcb, ROBÔ.kicad_sch]
